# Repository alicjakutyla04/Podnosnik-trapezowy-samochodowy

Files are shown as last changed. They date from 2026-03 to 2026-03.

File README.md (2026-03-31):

# Podnośnik trapezowy z napędem śrubowym

Projekt mechaniczny podnośnika trapezowego.
Projekt obejmuje pełny proces opracowania konstrukcji:

- modelowanie 3D części w **Siemens NX**
- wykonanie **rysunków technicznych**
- opracowanie **złożenia**
- przeprowadzenie **obliczeń wytrzymałościowych**
- dobór elementów znormalizowanych

Celem projektu było zaprojektowanie **specjalistycznego podnośnika trapezowego z napędem śrubowym**, przeznaczonego do ręcznego podnoszenia obciążeń.

---

# Wizualizacja złożenia

Projekt przedstawia mechanizm podnośnika trapezowego napędzanego śrubą trapezową.

Mechanizm działa poprzez obrót śruby za pomocą klucza nasadowego, co powoduje zmianę kąta między ramionami i podnoszenie lub opuszczanie konstrukcji.

Główne elementy układu:

- głowica
- stopa
- ramiona węższe
- ramiona szersze
- śruba napędowa
- nakrętka
- tuleja prowadząca
- łożysko wzdłużne
- sworznie

Projekt umożliwia **pełny demontaż konstrukcji oraz wymianę zużytych elementów**.

---

# Parametry konstrukcyjne

| Parametr | Wartość |
|---|---|
| Udźwig nominalny | **5100 N** |
| Maksymalna wysokość podnoszenia | **396 mm** |
| Wysokość przy obciążeniu nominalnym | **228 mm** |
| Odległość przyłożenia siły | **24 mm** |
| Współczynnik bezpieczeństwa | **1.7** |

Analiza statyczna została przeprowadzona dla najbardziej niekorzystnego przypadku pracy mechanizmu.

---

# Modelowanie CAD

Modele części zostały wykonane w programie **Siemens NX**.

Proces projektowy obejmował:

- modelowanie bryłowe wszystkich części
- budowę kompletnego złożenia
- weryfikację współpracy elementów
- przygotowanie dokumentacji technicznej

---

# Dokumentacja techniczna

Dla zaprojektowanych elementów wykonano **rysunki wykonawcze zgodne z zasadami rysunku technicznego**.

Dokumentacja zawiera:

- wymiary geometryczne
- tolerancje
- chropowatości powierzchni
- oznaczenia materiałowe
- przekroje techniczne

Przykładowe rysunki w projekcie:

- rysunek śruby napędowej
- rysunek tulei
- rysunek złożeniowy podnośnika

---

# Analiza wytrzymałościowa

W ramach projektu wykonano pełną analizę wytrzymałościową elementów konstrukcyjnych.

Sprawdzeniu poddano między innymi:

### Śruba napędowa

- naprężenia zredukowane
- warunek samohamowności gwintu
- naciski powierzchniowe

### Nakrętka

- zginanie
- ścinanie
- naciski powierzchniowe
- koncentrację naprężeń

### Ramiona

- zginanie
- ściskanie mimośrodowe
- stateczność
- wyboczenie

### Sworznie

- zginanie
- ścinanie
- naciski powierzchniowe

---

# Materiały

W projekcie zastosowano następujące materiały:

### Stal C45

Użyta w elementach konstrukcyjnych:

- ramiona
- sworznie
- nakrętka
- tuleja
- głowica
- stopa

### Stal C45 ulepszona cieplnie (~30 HRC)

Zastosowana dla:

- śruby napędowej

### BA1032

Użyta w tulejach zabezpieczających.

---

# Dobór elementów znormalizowanych

W projekcie zastosowano między innymi:

- łożysko kulkowe wzdłużne **SKF 51201**
- elementy złączne zgodne z normami

Dobór łożyska wykonano na podstawie nośności statycznej oraz średnicy śruby.

---

# Narzędzia

Projekt został wykonany przy użyciu:

- **Siemens NX** – modelowanie 3D i złożenia
- **NX Drafting** – rysunki techniczne
- klasycznych metod obliczeń wytrzymałościowych

---

# Autor

**Alicja Kutyła**  
Politechnika Warszawska

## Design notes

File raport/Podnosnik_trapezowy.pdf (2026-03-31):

## Wydział Mechaniczny Energetyki i Lotnictwa

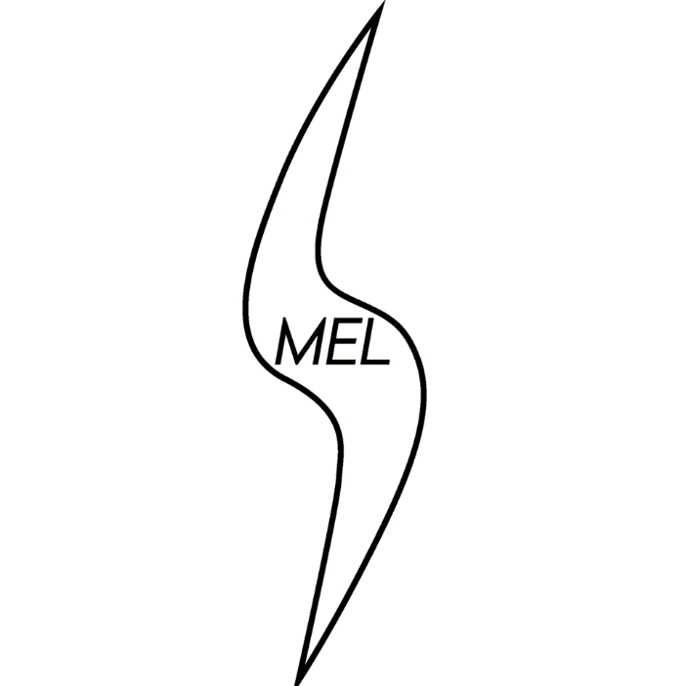
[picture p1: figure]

## Podstawy Konstrukcji Maszyn IV

# Dźwignik wyspecjalizowany trapezowy z napędem śrubowym

Wykonała | Sprawdził
Alicja Kutyła | dr inż. Jacek Gadomski

Warszawa 2026

# Spis treści

1. Założenia konstrukcyjne | 4
1.1. Rysunek Poglądowy | 4
1.2. Dane wyjściowe | 5
1.3. Materiały zastosowane w urządzeniu | 5
1.4. Współczynnik bezpieczeństwa | 6
2. Obciążenia | 6
2.1. Statyka | 6
2.2. Równania równowagi | 7
2.3. Reakcje w więzach | 8
2.4. Rozkłady składowych wysiłku | 9
3. Wytrzymałość konstrukcji | 10
3.1. Śruba | 10
3.2. Nakrętka | 12
3.3. Podparcie łożysk | 14
3.4. Ramiona | 15
3.5. Sworznie | 18
4. Dobór łożyska | 19

## 1.Założenia Konstrukcyjne

Celem projektu jest specjalistyczny podnośnik trapezowy z napędem śrubowym, napędzany ręcznie za pomocą klucza nasadowego z końcówką kwadratową. Ruch klucza napędza śrubę, smarowaną w celu zmniejszenia tarcia na gwincie, która pracuje z nakrętką i zmienia kąt rozwarcia między ramionami powodując unoszenie lub opuszczanie podnośnika. Przewidziane jest wielokrotne wykorzystanie podnośnika, więc możliwy jest pełen demontaż i wymiana zużytych bądź zniszczonych części.
1.1. Rysunek Poglądowy

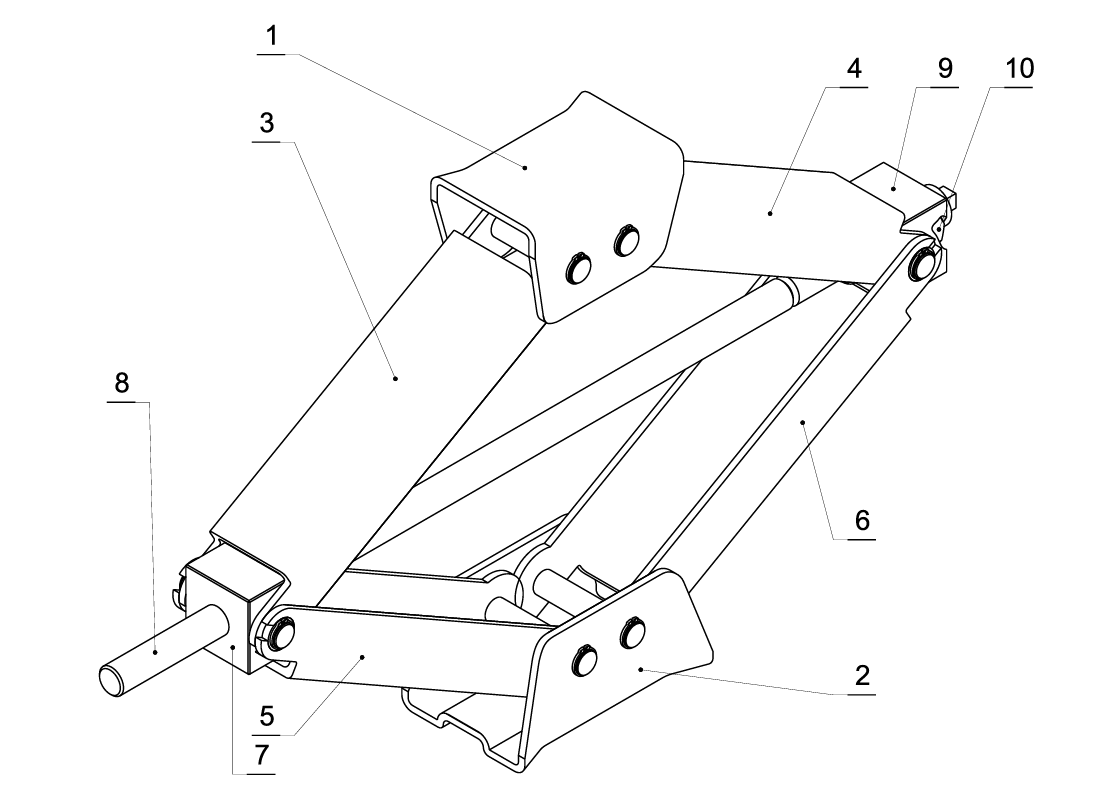
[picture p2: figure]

Główne części:
1.Głowica | 5.Ramię szersze A | 9. Tuleja
2.Stopa | 6. Ramię szersze B | 10. Łożysko
3. Ramie węższe A | 7. Nakrętka
4.Ramie węższe B | 8.Śruba napędowa

1.2. Dane wyjściowe

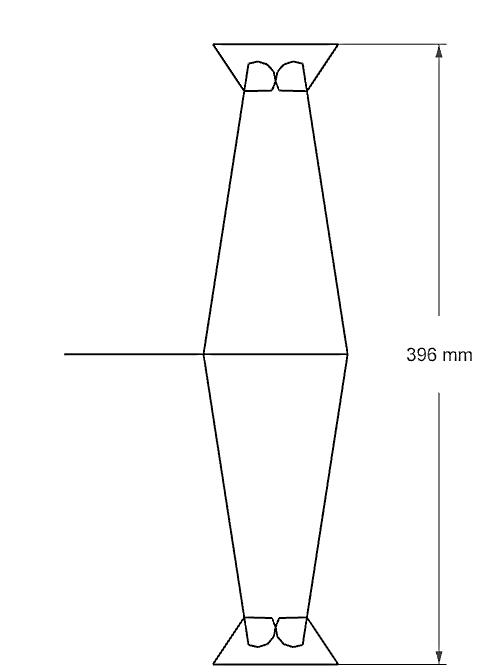
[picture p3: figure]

Założenia konstrukcyjne:

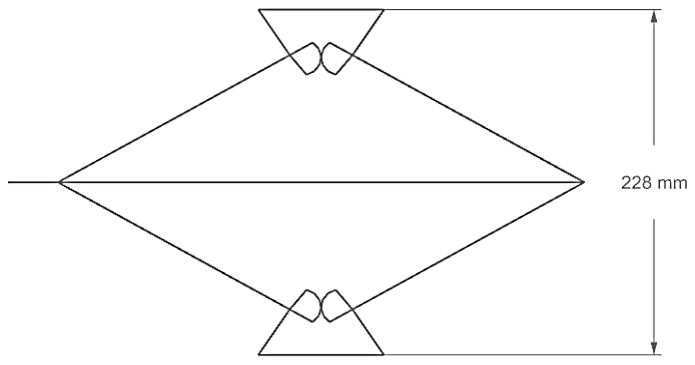
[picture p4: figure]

-udźwig nominalny | Q = 5100N
-wysokość maksymalna | H = 396mm
-wysokość, przy której obciążenie osiąga wartość Q | HQ = 228mm
-odległość miejsca przyłożenia obciążenia od środka głowicy | e = 24mm
1.3. Materiały zastosowane w urządzeniu

C45 (Re = 360 MPa, Rm = 610 MPa, wg PN-93/H-84019)
-sworznie
-nakrętka
-tuleja prowadzącą śrubę
-ramiona
-stopa
-głowica
C45 ulepszona cieplnie do około 30HRC (Na podstawie normy PN-EN ISO 18265 dokonano przeliczenia twardości na wartości wytrzymałościowe, co pozwoliło na przyjęcie Rm ≈ 900 MPa oraz Re ≈ 650 MPa do obliczeń wytrzymałościowych) -śruba napędowa
BA1032 (Rm = 550 MPa, kcj = 110MPa, wg PN-91/H-87026)

-tuleje zabezpieczające
Pozostałe części są znormalizowane i wykonane z materiału przewidzianego odpowiednią normą.
1.4. Współczynnik bezpieczeństwa

Projektowany podnośnik jest urządzeniem wyspecjalizowanym i będzie używany w kontrolowanych warunkach, stąd zdecydowano się przyjąć współczynnik bezpieczeństwa x=1,7.

## 2.Obciążenia

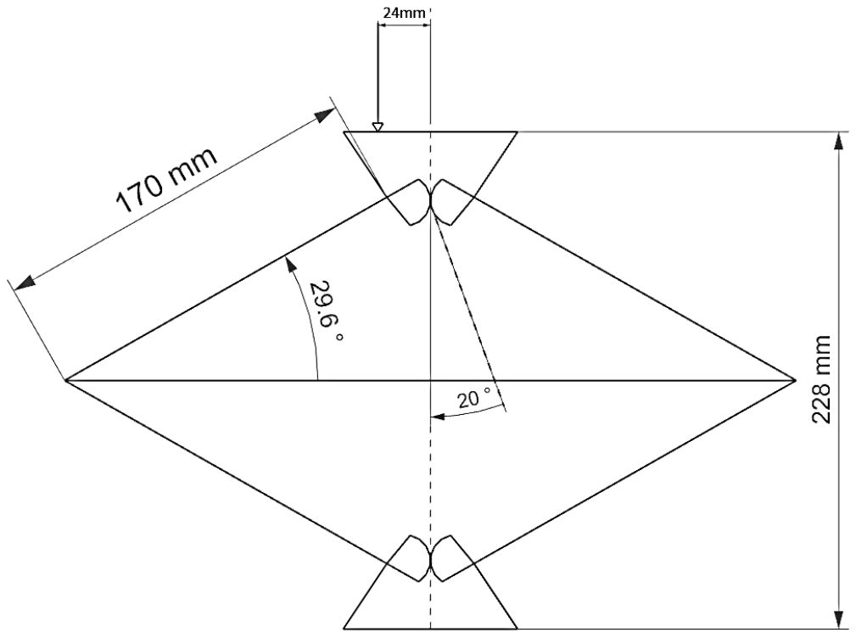
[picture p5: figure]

2.1. Statyka

Dane do obliczeń statyki:
Q = 5100N – udźwig nominalny
e = 24mm - odległość miejsca przyłożenia obciążenia od środka głowicy
l = 170mm – rozstaw między osiami otworów ramion podnośnika
r = 14mm – połowa średnicy podziałowej sektorów zębatych
φ = 29.6° - minimalny kąt, przy którym podnośnik przenosi nominalny ciężar α = 20° - kąt przyporu na sektorach zębatych o zarysie ewolwentowym

Obciążenia elementów podnośnika są w zakresie pracy podnośnika maksymalne dla minimalnego kąta, przy którym osiąga on obciążenie nominalne, tj. 29.6 stopnia. Dalsze analizy będą prowadzone dla sił wyznaczonych dla tego kąta.
2.2. Równania równowagi

Obciążenia w podnośniku są symetryczne względem śruby, wystarczy więc ułożyć równania równowagi i wyznaczyć reakcje dla jednej połowy podnośnika.

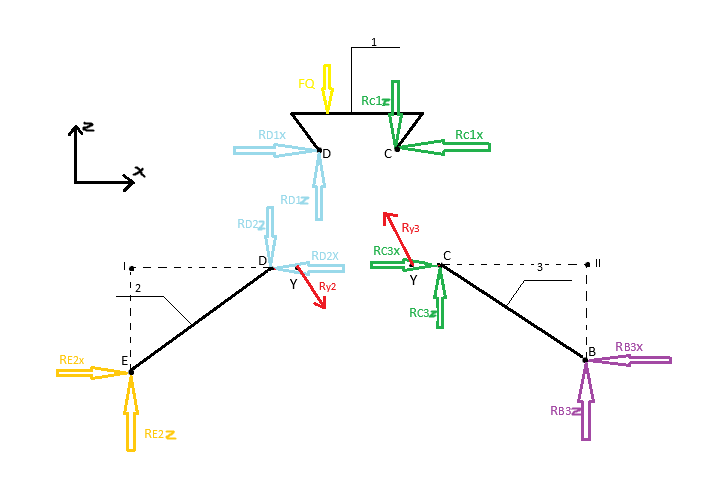
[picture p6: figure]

Odpowiednie równania równowagi:

RD1x = RD2x = RDx

RD1z = RD2z = RDz

RC1x = RC3x = RCx

RC1z = RC3z = RCz

∑MC = Q(e + r) − RDz ∙ 2r = 0

RDz = Q ∙ (e + r)/(2 ∙ r)

∑MD = Q(e − r) − PCz ∙ 2r = 0

RCz = Q ∙ (e − r)/(2 ∙ r)

∑MI = RE2x ∙ sin (φ) ∙ l − RD2z
- cos(φ) ∙ l + Ry2 ∙ cos(α) ∙ (l ∙ cos(φ) + r) = 0

∑MII = −RB3x ∙ sin (φ) ∙ l − RC3z
- cos(φ) ∙ l + Ry3 ∙ cos(α) ∙ (l ∙ cos(φ) + r) = 0

RE2x = RB3x

Ry3 = Ry2 = Ry

Ry =

(RDz+RCz) ∙ l ∙ cos (φ)
2 ∙ (l ∙ cos(φ) + r) ∙ cos (α)

∑ME = −RD2z
- l ∙ cos(φ) + RD2x ∙ l ∙ sin(φ) + Ry ∙ cos(α)
- (l ∙ sin (φ) ∙ tg(α) + r + l ∙ cos(φ)) = 0

RD2x =

RD2z

- l ∙ cos(φ) − Ry ∙ cos(α) ∙ (l ∙ sin (φ) ∙ tg(α) + r + l ∙ cos(φ)) l ∙ sin (φ)

RC3x = RC1x

RD1x = RC1x

RE2x =

RD2z

- l ∙ cos(φ) − Ry ∙ cos(α) ∙ (r + l ∙ cos(φ)) l ∙ sin (φ)

RB3x = RE2x

∑MY = −RE2z
- (l ∙ cos(φ) + r) + RE2x ∙ l ∙ sin(φ) + RD2z
- r = 0

RE2z =

RE2x ∙ l ∙ sin(φ) + RD2z
- r
l ∙ cos(φ) + r

∑MY = RB3z
- (l ∙ cos(φ) + r) − RB3x ∙ l ∙ sin(φ) + RC3z
- r = 0

RB3z =

RB3x ∙ l ∙ sin(φ) + RC3z
- r
(l ∙ cos(φ) + r)
2.3. Reakcje w więzach

Po rozwiązaniu powyższych równań otrzymano następujące wyniki:

RCz = 510N
RDz = 5610N
Ry = 2868,29N
RBx = REx = 4487,21N
RCx = RDx = 3506,2N
REz = 2185,31N

RBz = 2914,69N

2.4. Rozkłady składowych wysiłku

Wyznaczone reakcje wykorzystano do obliczenia sił normalnych, tnących i momentów gnących w ramionach podnośnika oraz wyznaczenia ich rozkładów wzdłuż długości.

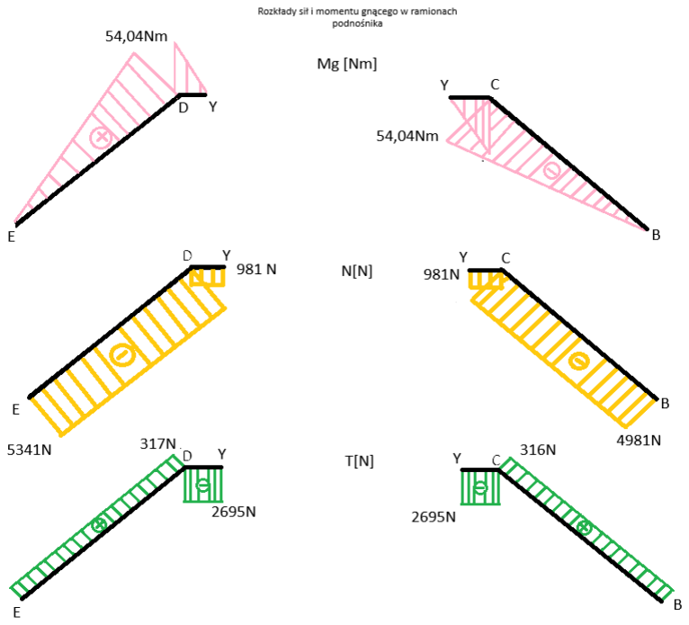
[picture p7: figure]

Siła rozciągająca śrubę wynosi Rs=2*REx = 8974,42N.

## 3.Wytrzymałość konstrukcji

3.1. Śruba

Wymiary gwintu S12x2 wg PN-ISO 2904
P = 2mm | d2 = D2 = 11,25mm | d1 = 10,26mm | D1=10,5mm
D=12mm | r=0,25mm e=0,53mm

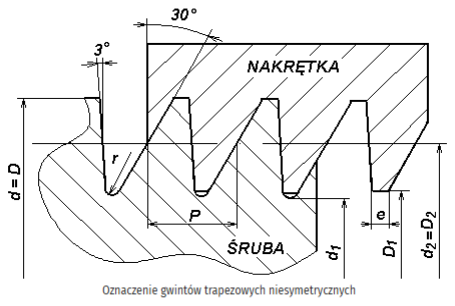
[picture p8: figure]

Do smarowania śruby należy dobrać taki smar, żeby współczynnik tarcia kinetycznego wynosił około 0,15.
Sprawdzenie samohamowności:

γ = arctg (

P
πd2

) = arctg (

2
3,14 ∙ 11,25) = 0,056557°

ρ′ = arctg (

μ
cosαr

) = arctg (
0,15
cos (

3,14
24 )

) = 0,150154°

ρ'>γ dla minimalnej założonej wartości więc śruba jest samohamowna. Moment oporu gwintu:

Ms = 0,5 ∙ RS

- d2tg(γ + ρ

′
) = 0,5 ∙ 8974,42 ∙ 0,01125 ∙ tg(0,206711) = 10,58621Nm

Fr = 0N Mg = 0Nm

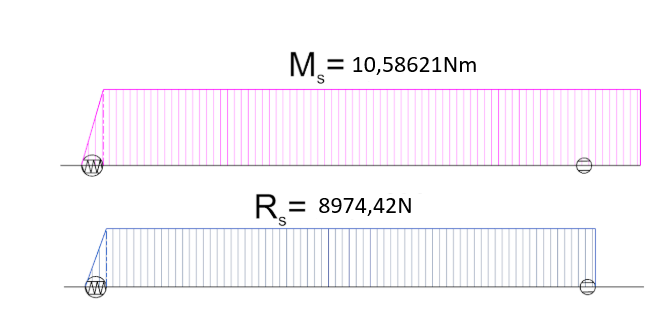
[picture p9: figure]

Naprężenia zredukowane w najbardziej wytężonym przekroju w śrubie wg hipotezy Hubera:

σz = √(

Rs
πd1

2
4

)

2
+ 3 (
Ms
πd1

3

16 )

2
= √(
8974,42
3,14 ∙ 0,01026²
4

)

2
+ 3(
10,58621
3,14 ∙ 0,01026³
16

)

2

= 108,603573MPa

kr =

Re
σz

=

650
108 ≈ 5,985 > x = 1,7

Zapas bezpieczeństwa jest większy od założonego współczynnika bezpieczeństwa, śruba spełnia więc wymagania wytrzymałościowe.
Jednak na śrubie występuje spęczenie i należy sprawdzić wytrzymałość również na nim. Średnica spęczenia D = 16mm
Średnica śruby d = 12mm

Powierzchnia spęczenia A =

π∙0,016²

4

−

π∙0,012²

4

= 8,792 ∙ 10⁻⁵

Wyliczone naciski powierzchniowe p = Rs
A

= 102,021MPa

Dopuszczalne naciski powierzchniowe pdop = 0,5 ∙ Re = 325Mpa

xwyl =

pdop
p

= 3,18 > 1,7

Śruba spełnia więc również wymagania wytrzymałościowe na spęczeniu.

3.2. Nakrętka

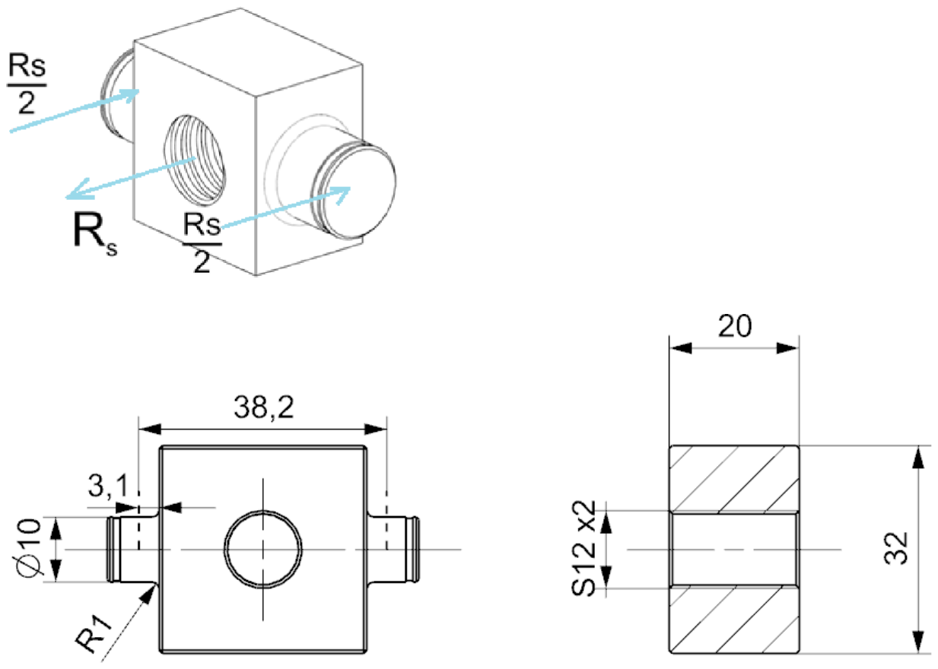
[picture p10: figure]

Nakrętka pracuje na zginanie. Największy moment gnący wystąpi pośrodku nakrętki i wyniesie:

Mgmax =

lr ∗ Rs
4

=

0,038 ∗ 8974,4
4

= 85,3Nm

gdzie lr = 38mm to szerokość węższego ramienia podnośnika.
Na nakrętce występuje karb, gdzie mogą się pojawić duże naprężenia. Moment gnący na nim:

Mgk =

Rs
2

∗ lk =

8974,4 ∗ 0,0031
2

= 13,9Nm

gdzie lk = 3,1mm to odległość karbu od punktu przyłożenia siły. Moment bezwładności na zginanie w przekroju środkowym:

Iś =

(0,032 − 0,012) ∗ 0,02³
12 | = 1,33 ∙ 10⁻⁸m⁴

Naprężenia w przekroju środkowym:

σś =

Mgmax ∗ z
Iś
= | 85,3 ∗ 0,01
| 1,33 ∗ 10⁻⁸ = 63,9MPa

Re = 360MPa ⇒ xo =

360
63,9

= 5,63 > x = 1,7

Nakrętka spełnia wymagania wytrzymałościowe ze względu na zginanie w przekroju środkowym. Jednak na karbie mogą pojawić się wysokie naprężenia i należy sprawdzić wytrzymałość również w tym miejscu.
Moment bezwładności na zginanie w przekroju karbu:

Ik =

π ∗ 0,01⁴
64 = 4,9 ∗ 10⁻¹⁰m⁴

Odczytany współczynnik kształtu: αk=1,5
Naprężenia na karbie wynoszą:

σk = αk

Mgk ∗ r
Ik

= 1,5 ∗

| 18,1 ∗ 0,005
| 4,9 ∗ 10⁻¹⁰ = 206MPa

x0 =

360
206 = 1,74 > x = 1,7

Nakrętka spełnia wymagania wytrzymałościowe na zginanie również w miejscu karbu. Pozostaje sprawdzić wytrzymałość na ścinanie i naciski powierzchniowe wystających walców. Największe naprężenia ścinające wystąpią na wewnętrznej stronie ścianek węższego ramienia.
Naprężenia ścinające:

τ =

Rs

n ∗

πd

2
4
= | 8974,4
2 ∗ | 3,14 ∗ 0,01²
| 4 = 57,1MPa

, gdzie n = 2 – powierzchnie ścinane ktj≈0,21*Re=75,6MPa > 57,1MPa,
, gdzie ktj – naprężenia dopuszczalne przy ścinaniu.
Nakrętka spełnia więc wymagania wytrzymałościowe ze względu na ścinanie. Naciski powierzchniowe:

p =

Rs
2d ∗ lt

=

| 8974,4
2 ∗ 0,01 ∗ 0,006 = 74,8MPa

Gdzie lt = 6mm – szerokość powierzchni styku tulei zabezpieczającej z walcem.
pdop ≈ 0,5Re = 180MPa ≫ 74,8MPa
gdzie pdop – dopuszczalne naciski powierzchniowe.

Nakrętka spełnia więc wymagania wytrzymałościowe ze względu naciski powierzchniowe.
3.3. Podparcie łożysk

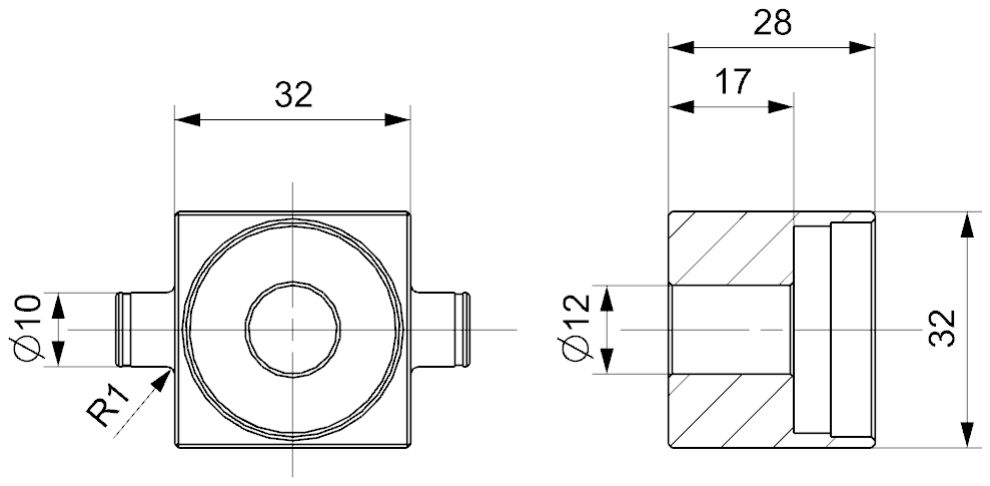
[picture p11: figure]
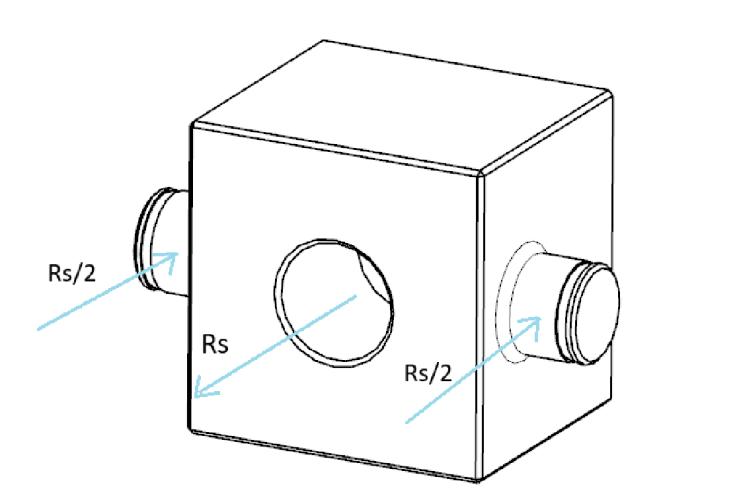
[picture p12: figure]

Tuleja prowadząca śrubę została wykonana z takiego samego materiału, podlega takiemu samemu obciążeniu a jej wymiary są prawie takie same bądź większe. Stąd niepotrzebna jest pełna analiza wytrzymałościowa tulei, gdyż nakrętka spełnia wymagania wytrzymałościowe a tuleja:
- w zakresie ścinania obliczenia są identyczne względem nakrętki
- w zakresie nacisków powierzchniowych obliczenia są identyczne względem nakrętki
- w zakresie zginania na karbie obliczenia są identyczne względem nakrętki.
Natomiast w zakresie zginania w przekroju największego obciążenia gnącego występuje dokładnie taki sam moment gnący:

Iś =

(0,032 − 0,012) ∗ 0,017³
12 | = 8,19 ∙ 10⁻⁹m⁴

σś =

Mgmax ∗ z
Iś
= | 85,3 ∗ 0,0085
| 8,19 ∗ 10⁻⁹ = 88,5MPa

Re = 360MPa ⇒ xo =

360
88,5
| = 4,07 > x = 1,7

a co za tym idzie, tuleja spełnia wymagania wytrzymałościowe ze względu na zginanie w przekroju środkowym.
3.4. Ramiona

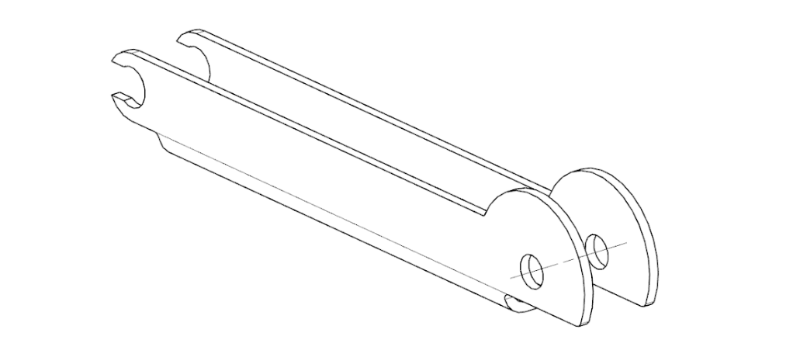
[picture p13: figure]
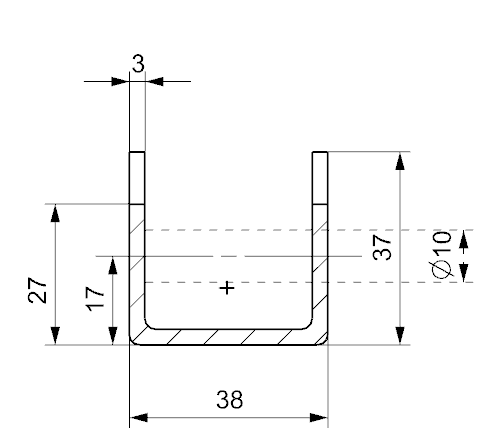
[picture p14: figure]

Ramiona pracują na zginanie i ściskanie mimośrodowe. Muszą też być stateczne oraz wytrzymywać naciski na powierzchni wewnętrznej otworów.

Momenty bezwładności na zginanie, pola przekroju i odległość punktu przyłożenia sił ściskających od środka ciężkości przekroju ramienia węższego, tj. bardziej wytężonego.
I= 1,901*10⁻⁸m⁴ | A = 2,58*10⁻⁴m² | e = 0,0067m
Obliczenia zostały wykonane dla najbardziej obciążonego ramienia.
Naprężenia maksymalne od zginania i ściskania mimośrodowego dla włókien górnych ramienia lewego:

σ =

P
A

+

Mg ∗ zg
I

−

| P ∗ e ∗ zg
I
| ==
| 5341 2,58 ∗ 10⁻⁴ + | 54,04 ∗ 0,0167 1,901 ∗ 10⁻⁸ − 5341 ∗ 0,0067 ∗ 0,0167
1,901 ∗ 10⁻⁸
= 99,6252MPa

i analogicznie dla włókien dolnych:

σ =

P
A

+

Mg ∗ zd
I

−

| P ∗ e ∗ zd
I
| ==
| 5341 2,58 ∗ 10⁻⁴ − | 54,04 ∗ 0,0103 1,901 ∗ 10⁻⁸ + 5341 ∗ 0,0067 ∗ 0,0103
1,901 ∗ 10⁻⁸
= −27,976MPa
gdzie zg = 16,7mm, zd = 10,3mm – odległość dolnej i górnej krawędzi kształtownika od środka ciężkości przekroju.
Pozostałe 2 ramiona mają większy przekrój i moment bezwładności, a takie same obciążenia, zatem nie trzeba sprawdzać ich wytrzymałości. Wszystkie ramiona wytrzymają więc naprężenia pochodzące od ściskania mimośrodowego i zginania.
| Re = 360MPa ⇒ xo =

360
| | 100 = 3,6 > x = 1,7

Sprawdzenie stateczności wg normy PN-80/B-03200: Wytrzymałość obliczeniowa:

R =

Re
γs

, Re = 360MPa, γs = 1,2 dla 355 < Re < 460 ⟹ R =

| | 360
1,2

= 300MPa

Sprawdzenie wyboczenia giętno-skrętnego:
| b ≤ 15g√
| 215 R

⟹ 27 ≤ 15 ∗ 3 ∗ √
| | 215 300 = 38,1

gdzie b = 27mm – szerokość półki kształtownika, g = 3mm – grubość półki Warunek jest spełniony, więc wyboczenie giętno-skrętne nie jest wymiarujące. Sprawdzenie stateczności miejscowej:

φ = 90 − 30ψ = 98,42
| ψ = σ2 σ1
= −0,28

λ

∗ = 3

b
g

≤ φ√
215
R

⟹ 27 ≤ 98,42 ∗ √
215
300 = 83,322

Warunek jest spełniony, więc stateczność miejscowa nie jest wymiarująca. Sprawdzenie wyboczenia giętnego:

λ =

lw
i

=

l ∗ μ
√
I
A

=

0,17 ∗ 1
√
1,901 ∗ 10⁻⁸
2,58 ∗ 10⁻⁴

= 18,64

gdzie μ = 1 – współczynnik zależny od zamocowania ramienia I – promień bezwładności przekroju

λp =

1675
√R

=

1675
√300

= 96,7 ⟹ 0,2λp = 19,32 > λ = 18,64

Współczynnik wyboczeniowy mw = 1; xr = 1,7

σr =

P ∙ mw
A

+

Mg + P ∙ e
Wg = 99,6MPa ≤ 1.05 ∙

R
xr

= 185MPa

σsc =

P ∙ mw
A

+

(Mg + P ∙ e) ∙

300 + 2λ
1000
Wd | = 37,1Mpa ≤

R
xr

= 178MPa

Sprawdzenie stateczności drugą metodą na podstawie opracowania prof. Z. Brzoski „Stateczność płyt i powłok”.

E = 2,07 ∙ 10⁵MPa | v = 0,3
Dane geometryczne: | a=0,17m | b=0,027m | g=0,003
Z wykresu ,,Naprężenia krytyczne płyty ściskanej przy różnych warunkach brzegowych”
zostały odczytane wartości współczynnika ξ – odpowiednio ξ1 = 1,3 | , | ξ2 = 5,1

σkr1 =

π

2
12(1 − v

2)

- ξ1 ∙ E ∙ (

δ
b

)

2
= 3000MPa

σkr2 =

π

2
12(1 − v

2)

- ξ2 ∙ E ∙ (

δ
b

)

2
= 11800MPa

σred = √σr
2 + σsc

2 = 106MPa

σred < σkr1 i σkr2

Ramiona są stateczne.

3.5. Sworznie

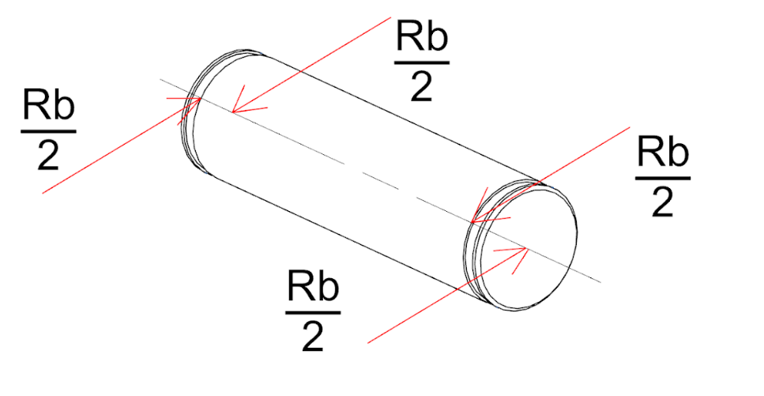
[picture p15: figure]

W podnośniku znajdują się cztery sworznie, różniące się jedynie długością, która nie wpływa na obciążenia w nich, są takie same w obu. Największa siła jaka na nie działa to P = 5341,3N.
Maksymalny moment gnący wynosi:

Mgmax =

P ∗ ls
2

=

5341,3 ∗ 0,003
2

= 8,02Nm

gdzie ls = 3mm – odległość między środkami naciskających na niego ramienia i stopy/głowicy.
Moment bezwładności na zginanie wynosi:

I =

πd

4
64 =

3,14 ∗ 0,01⁴
64 = 4,9 ∗ 10⁻¹⁰m⁴

Maksymalne naprężenia na sworzniu wynoszą:

σmax =

Mgmax ∗ r
I

=

8,02 ∗ 0,005
4,9 ∗ 10⁻¹⁰ = 81,61MPa
Re = 360MPa ⇒ xo = | 360
| 81,61 = 4,41 > x = 1,7

Sworznie spełniają więc wymagania wytrzymałościowe ze względu na zginanie. Następnie należy sprawdzić ścinanie:

τ =

P

n ∗

πd

2
4

=

| 5341,3

2 ∗

3,14 ∗ 0,01²

| 4 = 34MPa

gdzie n = 2 – powierzchnie ścinane
ktj ≈ 0,21Re = 75,6MPa > 34MPa
Sworznie spełniają więc wymagania wytrzymałościowe ze względu na ścinanie. Pozostaje sprawdzić naciski powierzchniowe:

p =

P
2d ∗ g

=

5341,3
2 ∗ 0,01 ∗ 0,003 = 89,02MPa gdzie g = 3mm – szerokość powierzchni naciskającej na sworzeń
pdop ≈ 0,5Re = 180MPa > 89,02MPa
Sworznie spełniają więc wymagania wytrzymałościowe ze względu naciski powierzchniowe.
4. Dobór łożyska

Łożysko kulkowe wzdłużne jednokierunkowe dobrano tak, aby miało średnicę wewnętrzną pasującą do średnicy śruby napędowej (12mm), a jego nośność statyczna spełniała warunek C0 > 1.5*Rs

1.5 ∗ Rs = 1.5 ∗ 8974,42N = 13461,63N
Wybrano więc z katalogu SKF pasujące wymiarami łożysko 51201 o nośności statycznej C0=20800N, które spełnia ten warunek.

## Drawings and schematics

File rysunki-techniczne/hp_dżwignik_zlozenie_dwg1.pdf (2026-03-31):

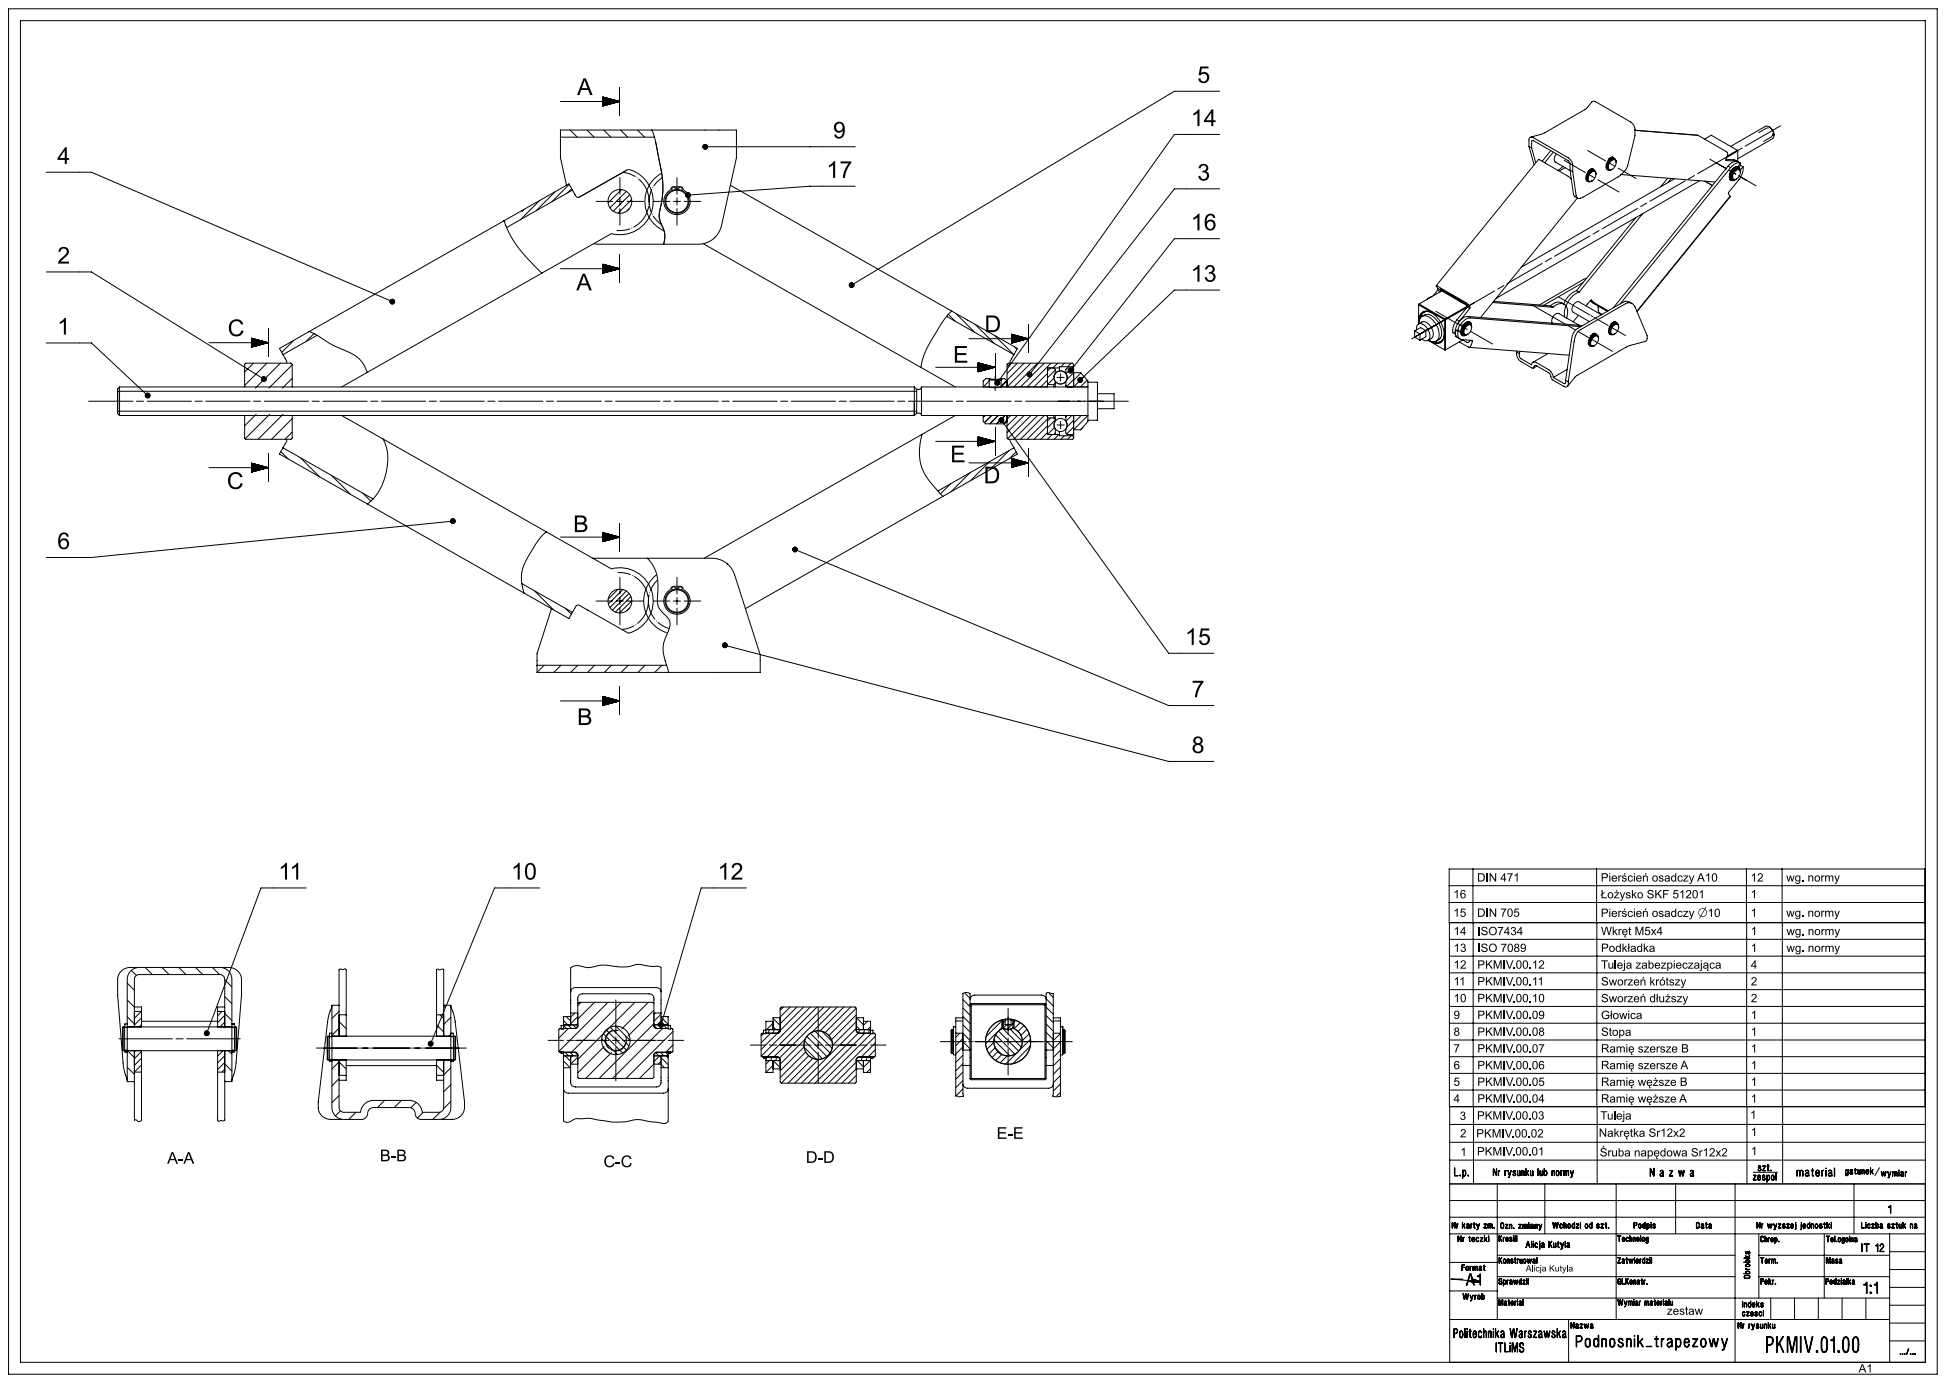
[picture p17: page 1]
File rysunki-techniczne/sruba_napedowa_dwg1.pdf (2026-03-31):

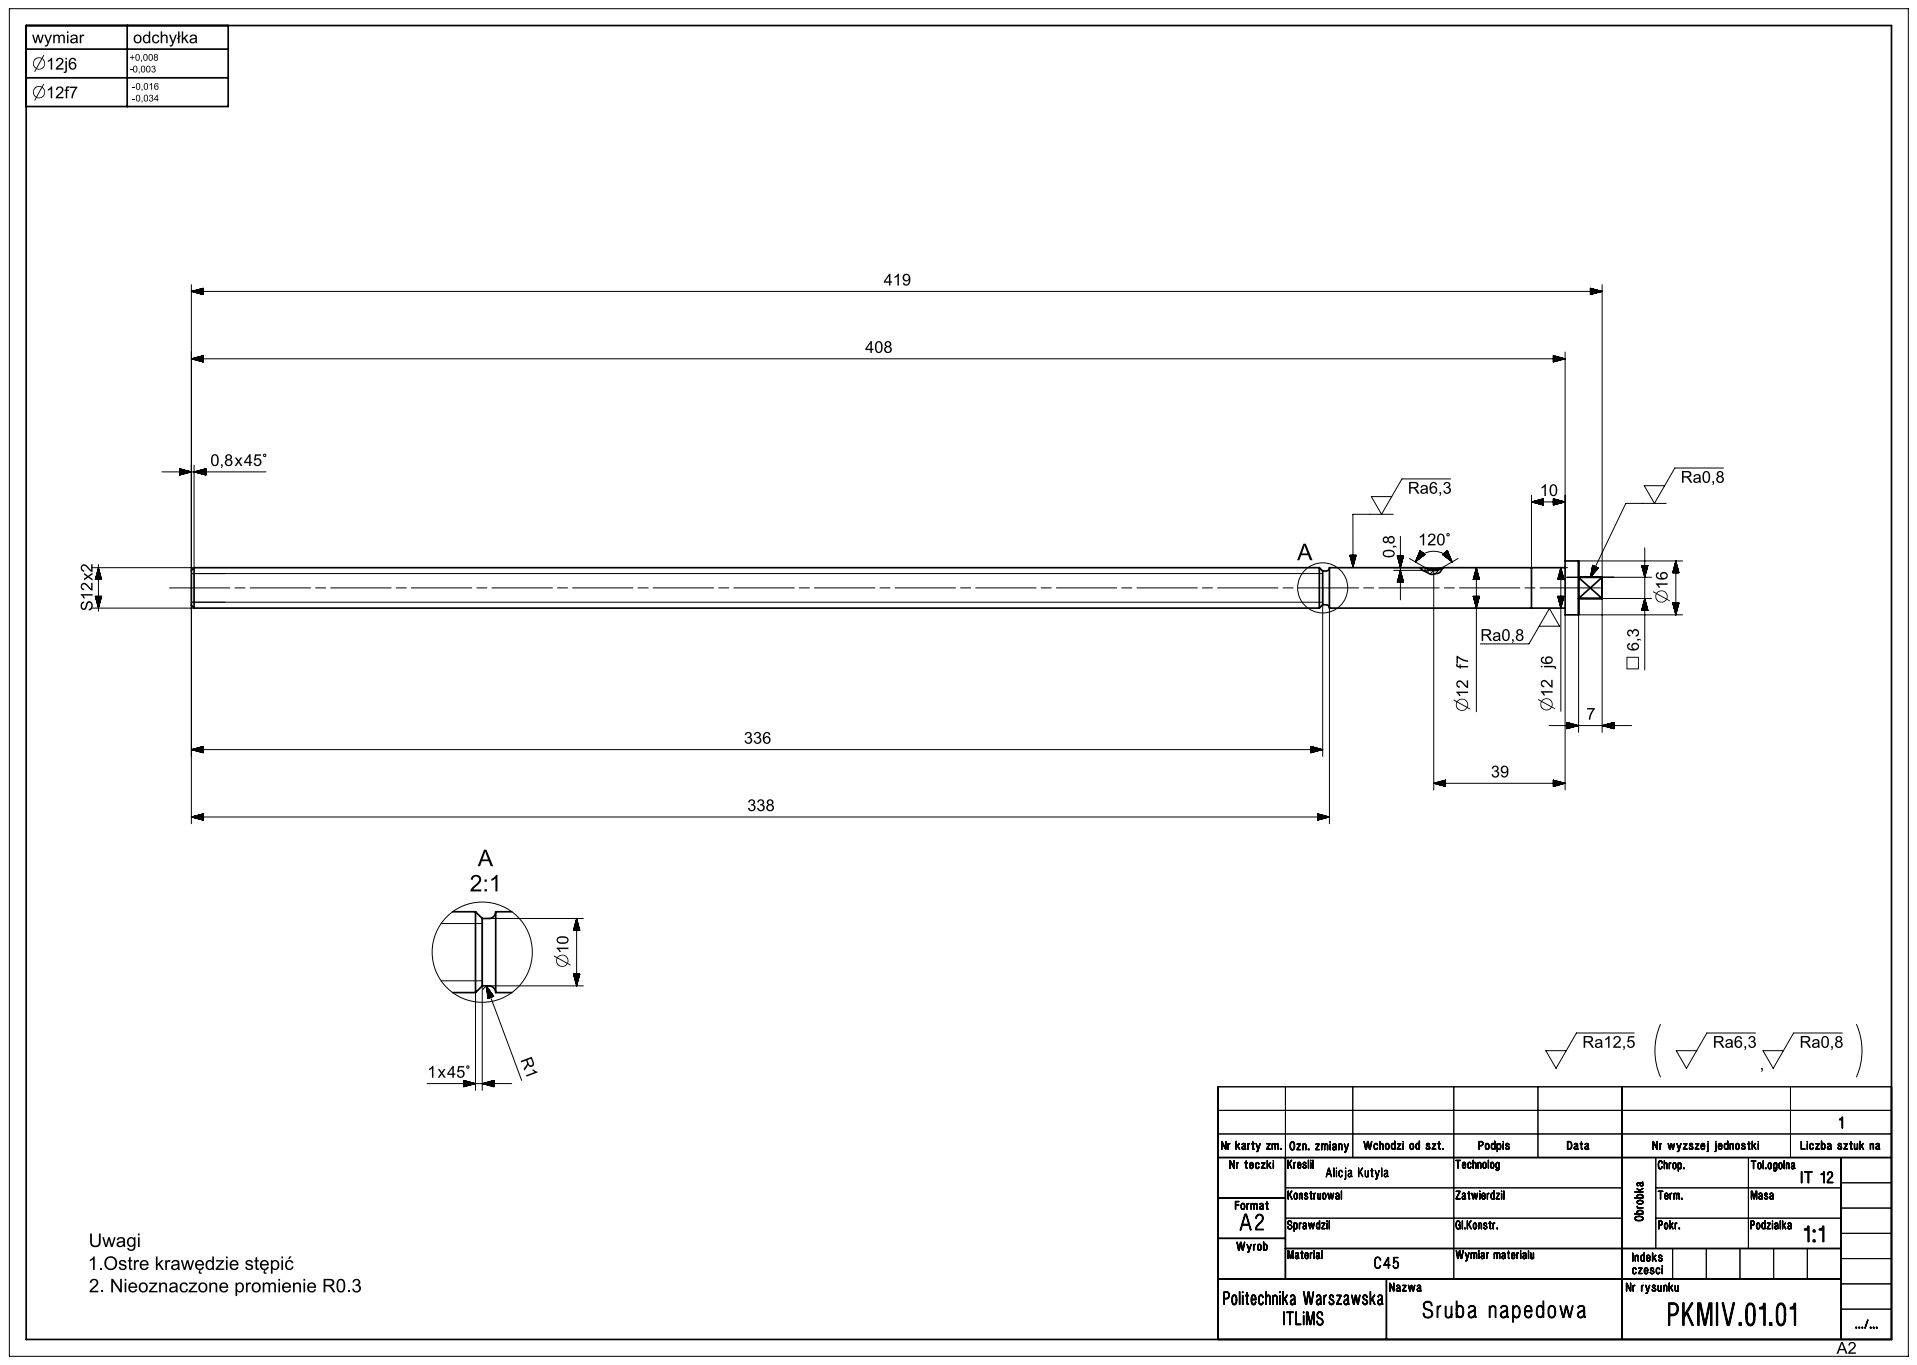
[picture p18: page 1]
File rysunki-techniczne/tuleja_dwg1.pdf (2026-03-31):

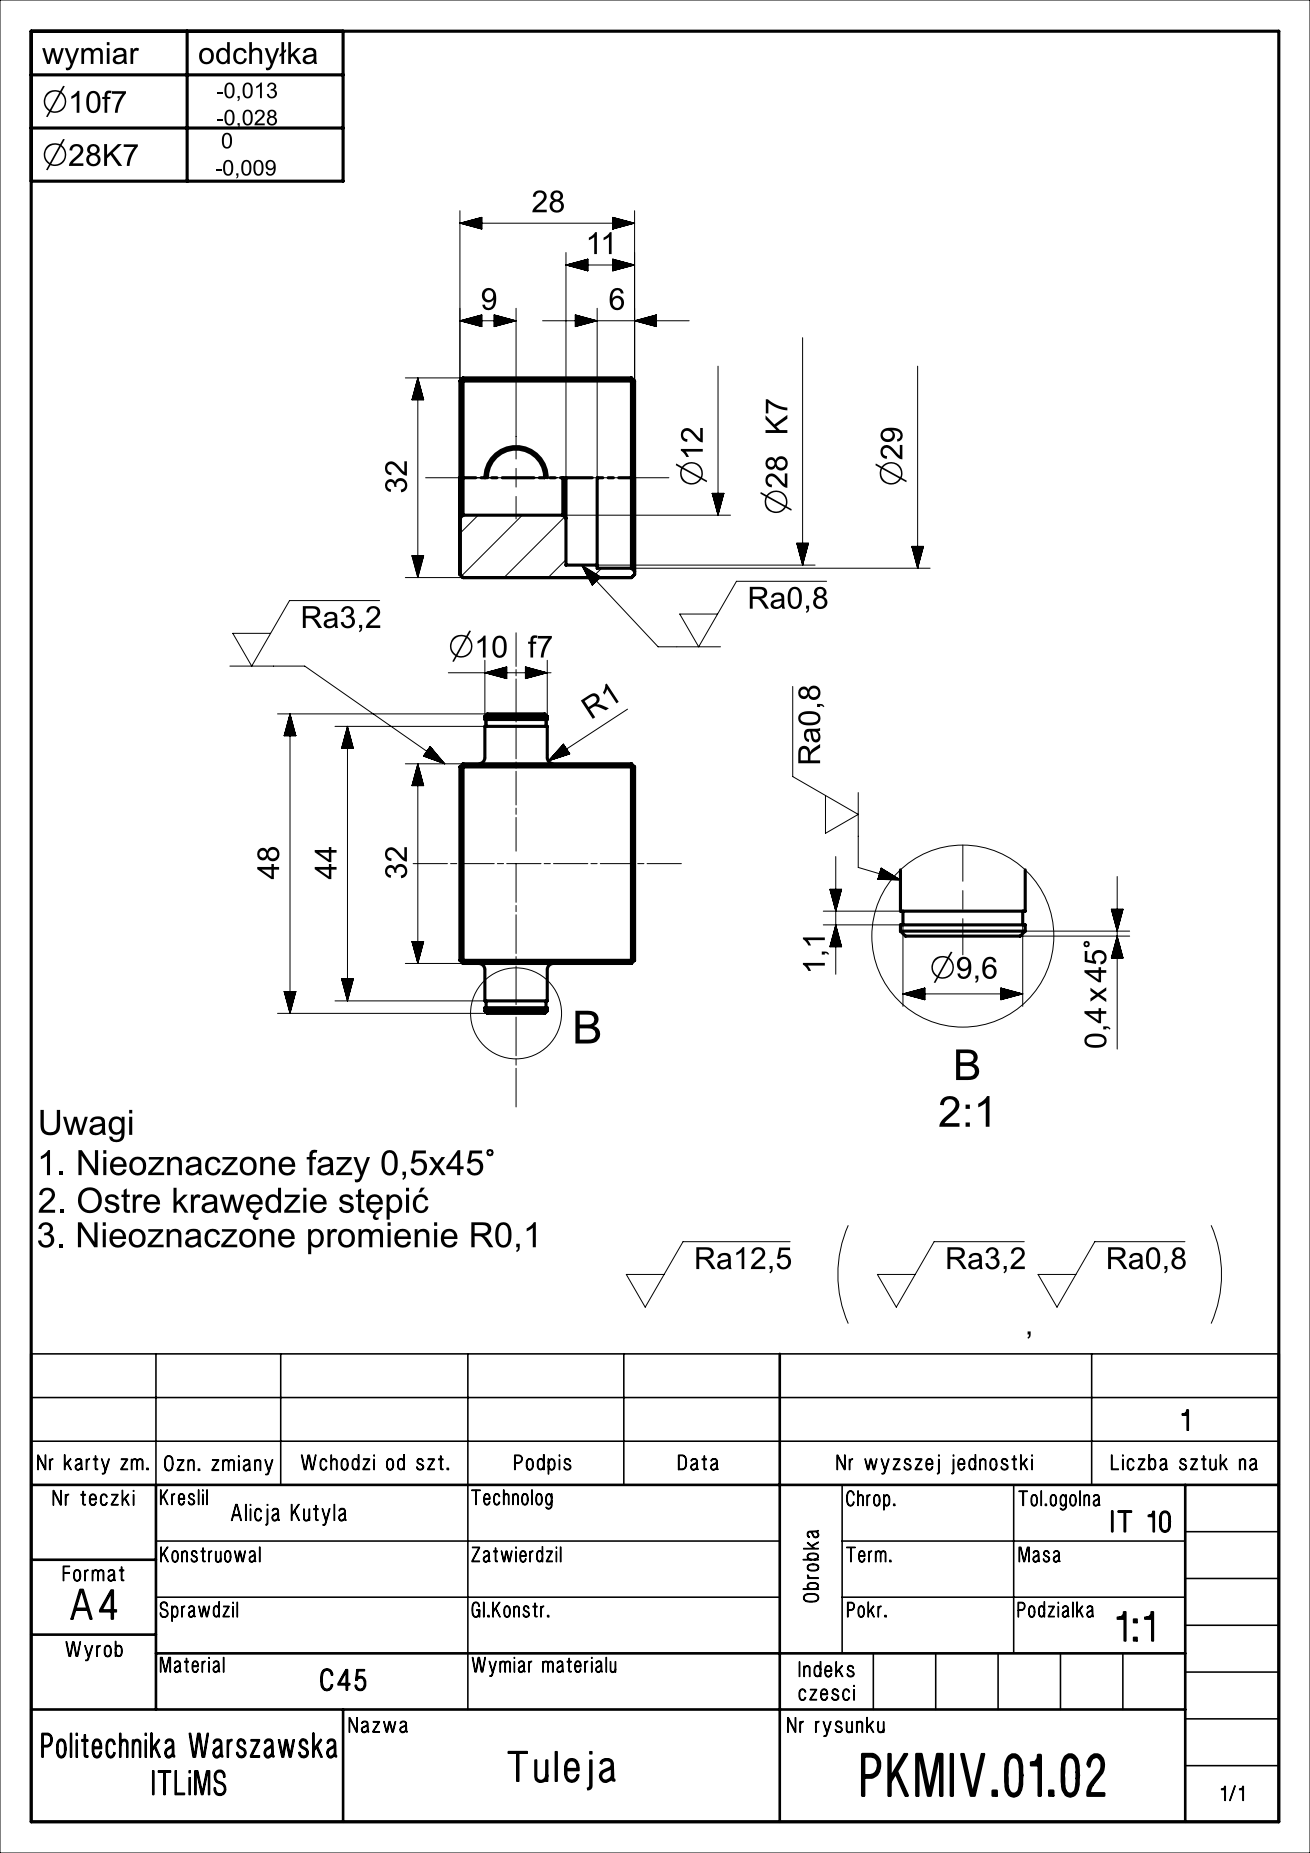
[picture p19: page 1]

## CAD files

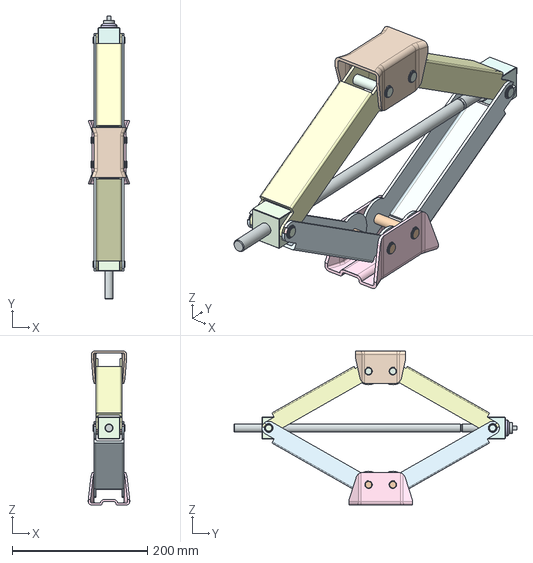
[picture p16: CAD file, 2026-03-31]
modele3D/dżwignik_assembly.stp
61.5 x 419.0 x 228.0 mm

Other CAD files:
modele3D/dżwignikass4.prt
modele3D/głowica.prt
modele3D/nakrętka.prt
modele3D/pierscien.prt
modele3D/pierscien_na_srube.prt
modele3D/ramiemniejsze1.prt
modele3D/ramiemniejsze2.prt
modele3D/ramiewieksze1.prt
modele3D/ramiewieksze2.prt
modele3D/skf_bearing_51201_2_x_t.prt
modele3D/sruba_napedowa.prt
modele3D/stopa.prt
modele3D/sworzen_długi.prt
modele3D/sworzen_krotki.prt
modele3D/sworzen_lozysko.prt
modele3D/tuleja.prt
modele3D/tulejastozkowa.prt
modele3D/wkret.prt
rysunki-techniczne/Tuleja_dwg1.prt
rysunki-techniczne/dżwignik_zlozenie_dwg1.prt
rysunki-techniczne/sruba_napedowa_dwg1.prt
